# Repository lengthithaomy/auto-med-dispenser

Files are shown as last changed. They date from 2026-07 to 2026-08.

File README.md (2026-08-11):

# 💊 AutoDose — Automatic Medication Dispenser

> A standalone pill dispenser I built for the **VoltHacks Hackathon 2026**. It is designed to help people, especially elderly users, remember to take the right medication at the right time without needing a phone, Wi-Fi, or a subscription.

<p align="center">
  AutoDose device
</p>

<p align="center">
  <a href="https://youtu.be/d-JQTOUDefM?si=IusnsNRkliP58Vxm">▶️ Check out the video</a>
</p>

I designed the 3D-printed parts in **Autodesk Inventor** and wrote the firmware using the **Arduino IDE**.

Since I originally built AutoDose for use at home, I made the day labels on the tray and the reminder audio in Vietnamese. I've also included the original Inventor file, so you can modify the tray if you want to use a different language. The reminder sounds can also be replaced — see [Changing the Reminder Sound](#-changing-the-reminder-sound).

---

## 📖 What is AutoDose?

I wanted to make a pill dispenser that could do more than just remind someone that it was time to take their medication.

AutoDose stores a week's worth of morning and evening doses. At the scheduled time, it rotates the correct compartment into position and releases the pill. It then uses an IR sensor to check whether the pill was actually picked up.

If it isn't, the device keeps reminding the user every 30 minutes.

The whole thing runs locally on an Arduino. There's no app, internet connection, account, or subscription involved.

---

## ✨ Features

* 🗓️ **15-compartment rotating tray** — 14 compartments for AM/PM doses across 7 days, plus one slot used for calibration/reset.
* ⚙️ **Drift-free tray positioning** — a 7.5:1 gear reduction makes each compartment exactly 2,048 motor steps apart.
* 👁️ **Pill pickup detection** — a TCRT5000 IR sensor checks both the pill drop and whether the user has picked it up.
* 🔊 **Sound, light, and LCD reminders** — the DFPlayer Mini plays a voice reminder, while an LED and 16x2 LCD show the current status.
* ⏰ **Repeating reminders** — if the pill isn't picked up, the reminder repeats every 30 minutes.
* 🔌 **Works without the internet** — the DS3231 RTC keeps track of the time, so the dispenser doesn't need Wi-Fi or a phone.

---

## 🔩 Bill of Materials

| Component | Qty | Operating Voltage | Function |
| --- | :-: | :---: | --- |
| Arduino Uno R3 |  1  | 5V | Main controller |
| RTC DS3231 |  1  | 5V | Keeps track of the time |
| 28BYJ-48 Stepper Motor + ULN2003 Driver |  1  | 5V | Rotates the tray |
| TCRT5000 IR Reflective Sensor |  1  | 3.3–5V | Detects pill drop and pickup |
| LCD 1602 (I2C) |  1  | 5V | Shows the time and system status |
| DFPlayer Mini + 0.5W 8Ω Speaker |  1  | 3.2–5V | Plays voice reminders |
| Red LED + 220Ω Resistor |  1  | 2V | Indicates an active reminder |
| 5V USB Power Supply |  1  | 5V | Powers the device |

---

## ⚙️ Mechanical & Gear System

One of the biggest problems I ran into was keeping the tray aligned.

The 28BYJ-48 has 4,096 steps per full rotation. If the motor directly rotated the 15-slot tray, the number of steps per compartment would be:

$$
\frac{4096}{15} \approx 273.07 \text{ steps/slot}
$$

That isn't an integer, so the tray would gradually lose alignment after repeated movements.

### The 7.5:1 gear reduction

I solved this by adding a **7.5:1 gear reduction** between the motor and the tray.

That gives:

$$
4096 \times 7.5 = 30{,}720
$$

steps for one full tray rotation.

Since the tray has 15 compartments:

$$
\frac{30{,}720}{15} = 2{,}048
$$

So every compartment is exactly **2,048 motor steps** apart.

This means the motor always lands on the same position for each compartment instead of accumulating a small positioning error every time the tray moves.

---

## 🔄 How It Works

<p align="center">
  Workflow diagram
</p>

### 1. Scheduling

The Arduino checks the current time from the DS3231 against the scheduled dosing times:

* **07:00** — morning dose
* **19:00** — evening dose

### 2. Dispensing

When it's time, the stepper motor moves **2,048 steps** to bring the correct compartment above the drop chute.

### 3. Reminder

The pill falls into the receiving tray. The LED turns on and the DFPlayer Mini plays a voice reminder.

### 4. Checking if the pill was picked up

The IR sensor monitors the receiving area.

* ✅ **Pill picked up** — the system detects the change, plays a confirmation message, turns off the LED, and records the dose as completed.
* ⏳ **Pill still there** — the reminder stays active and repeats every 30 minutes until the pill is picked up.

---

## 🚀 Getting Started

1. Assemble the circuit using the components listed in the [Bill of Materials](#-bill-of-materials).
2. Upload the Arduino sketch from `/code` to the Arduino Uno.
3. Set the current date and time on the DS3231.
4. Fill the 14 medication compartments (AM/PM × 7 days). Leave the calibration slot empty.
5. Plug in the 5V USB power supply.
6. The dispenser will start checking the schedule automatically.

---

## 🔊 Changing the Reminder Sound

The reminder audio is stored on the **DFPlayer Mini**.

The included audio files are in Vietnamese because that's what I use at home. You can replace them with your own recordings if you want different languages or sounds.

See the relevant instructions in the project files for the required filenames and SD card setup.

---

## 🛠️ Things I'd Like to Improve

There are still quite a few things I'd change if I had more time:

* Add support for multiple users
* Add a battery backup so the device keeps running during a power outage
* Make different tray sizes for different medication schedules
* Add an optional caregiver app while keeping the device usable without it
* Improve the mechanical design and make the 3D-printed parts easier to assemble

---

## 📜 License

This project is licensed under the MIT License. See the [LICENSE](LICENSE) file for details.

---

## 🙏 Acknowledgments

Built for the **VoltHacks Hackathon 2026** as a first-year college project.

This started as something I wanted to make for use at home, and the hackathon gave me a good excuse to actually build it.

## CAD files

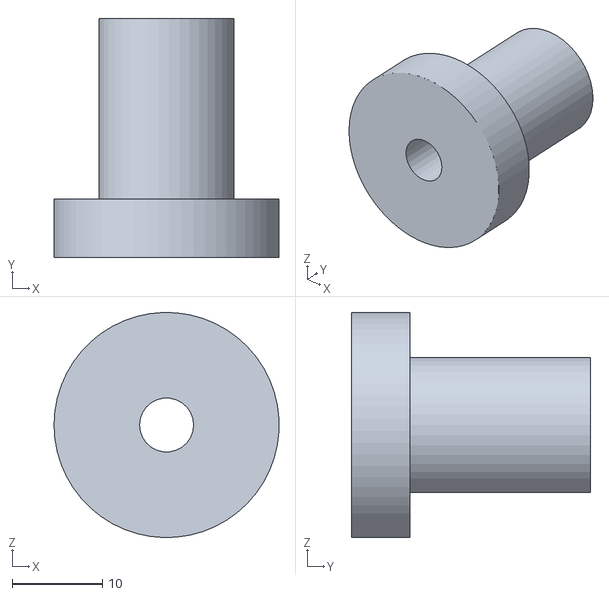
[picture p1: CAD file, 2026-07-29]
cad/stl-files/Trục-trung-tâm.stl
25.0 x 26.5 x 25.0

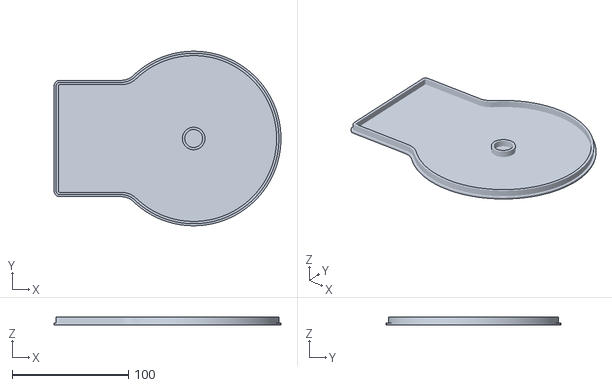
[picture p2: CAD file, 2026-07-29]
cad/stl-files/Đế.stl
195.0 x 150.0 x 6.60

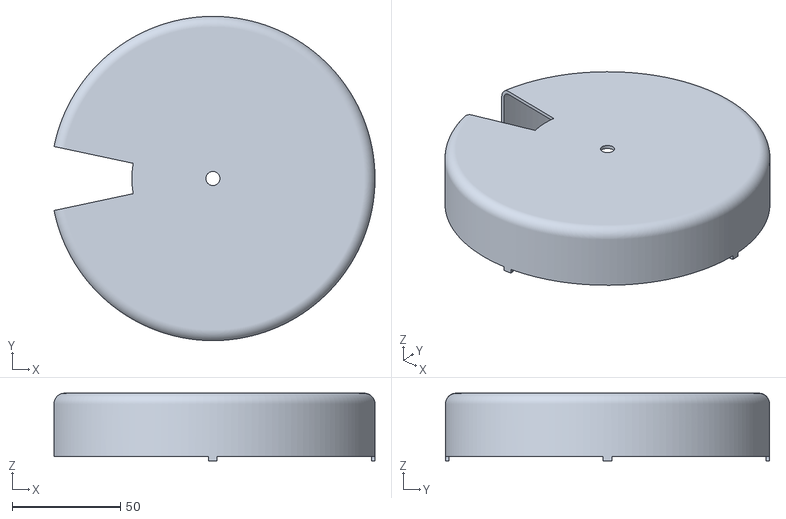
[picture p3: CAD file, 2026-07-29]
cad/stl-files/Nắp.stl
148.5 x 150.0 x 31.3

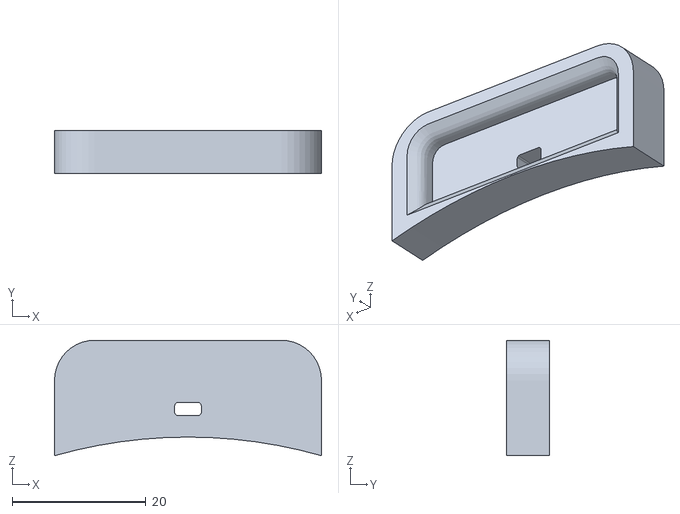
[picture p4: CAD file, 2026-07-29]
cad/stl-files/Khay-hứng-thuốc.stl
40.0 x 6.50 x 17.3

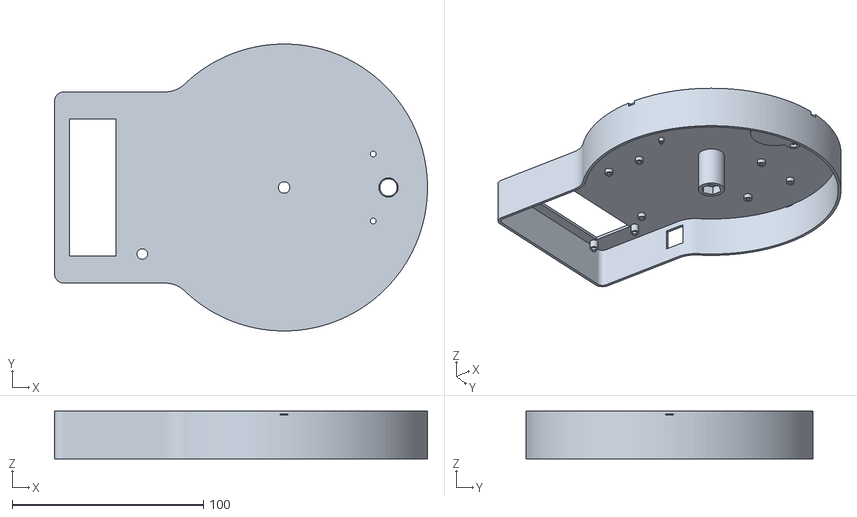
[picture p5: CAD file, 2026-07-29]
cad/stl-files/Base.stl
195.0 x 150.0 x 25.0

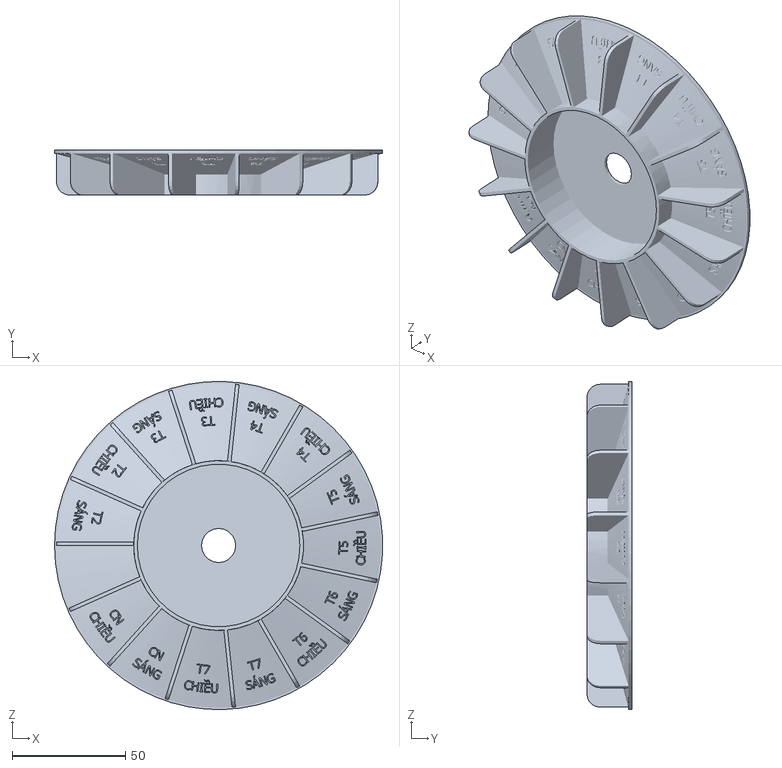
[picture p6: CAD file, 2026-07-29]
cad/stl-files/Khay-đựng.stl
144.9 x 20.0 x 144.9

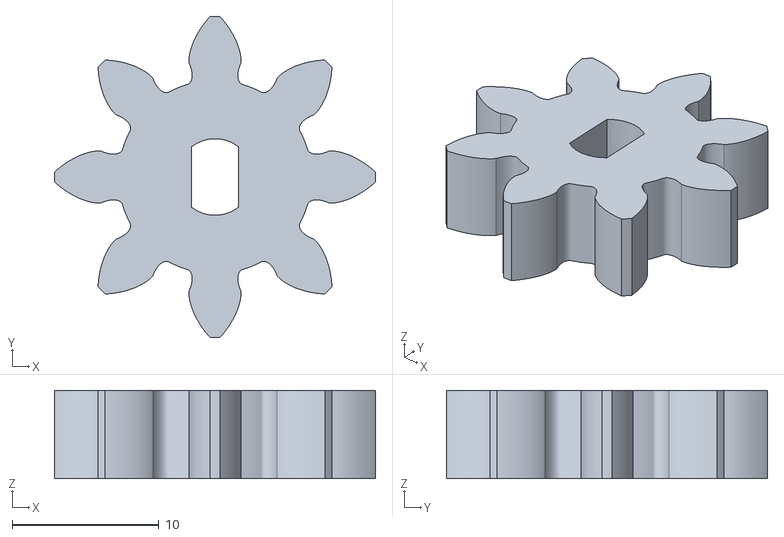
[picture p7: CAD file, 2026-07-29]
cad/stl-files/Bánh-răng-nhỏ.stl
21.8 x 21.8 x 6.00

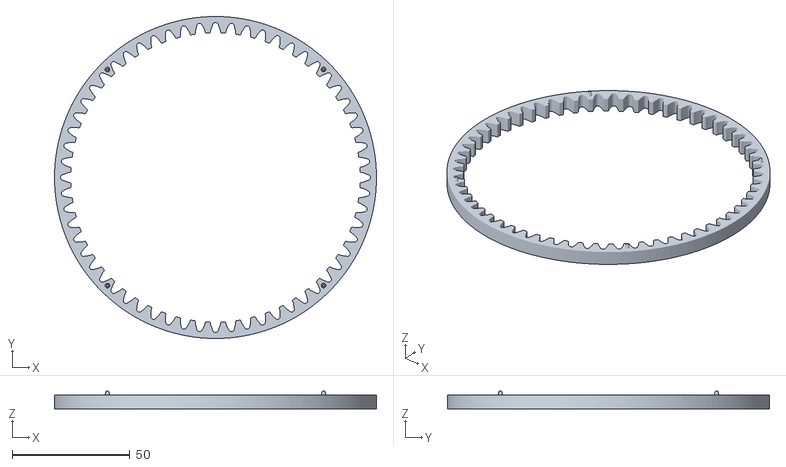
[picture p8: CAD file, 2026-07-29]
cad/stl-files/Bánh-răng-lớn.stl
136.6 x 136.6 x 7.60

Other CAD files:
cad/customize-tray/Khay-đựng.ipt

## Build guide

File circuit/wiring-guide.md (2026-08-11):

# 🔌 Circuit & Wiring

This folder contains the wiring diagram for AutoDose.

The diagram was made in Fritzing and shows how the Arduino Uno connects to the sensors, display, RTC, stepper motor, and DFPlayer Mini.

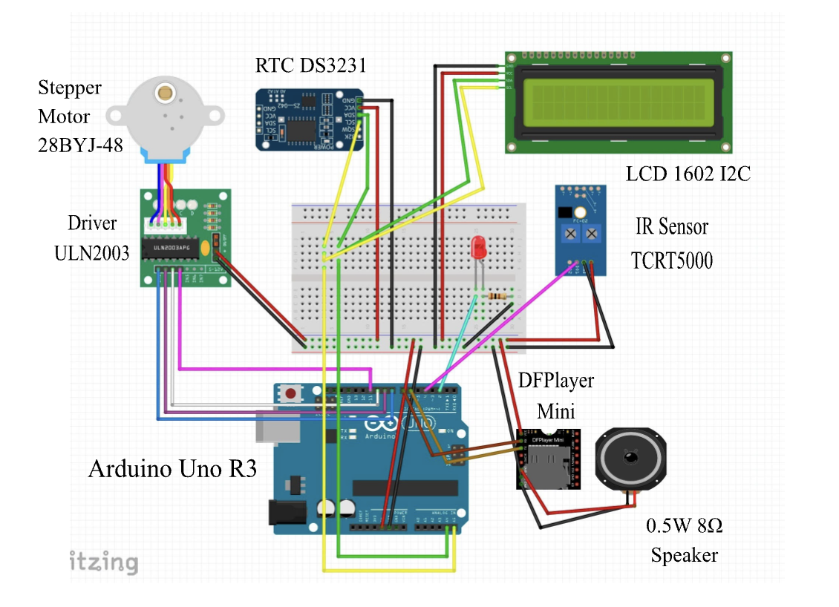
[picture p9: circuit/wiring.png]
AutoDose wiring diagram


## Pin Connections

| Component | Pin | Arduino Uno |
|---|---|---|
| ULN2003 | IN1 | D8 |
| ULN2003 | IN2 | D9 |
| ULN2003 | IN3 | D10 |
| ULN2003 | IN4 | D11 |
| TCRT5000 | OUT | D4 |
| LED | Anode (+) | D2 |
| DFPlayer Mini | RX | D7 |
| DFPlayer Mini | TX | D6 |
| DS3231 | SDA | A4 |
| DS3231 | SCL | A5 |
| LCD 1602 I2C | SDA | A4 |
| LCD 1602 I2C | SCL | A5 |

The DS3231 and LCD both use I2C, so they share the same SDA and SCL pins.

## Power

The modules are powered from the Arduino's 5V and GND connections. Make sure all modules share a common ground.

The 28BYJ-48 stepper motor is connected through the ULN2003 driver board rather than directly to the Arduino.

## Notes

The wiring shown here is based on the version of AutoDose I built for the VoltHacks Hackathon 2026. If you are rebuilding it yourself, double-check the pin connections against the Arduino code before powering everything on.

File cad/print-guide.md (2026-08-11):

# 🖨️ 3D Printing & CAD Files

AutoDose CAD model

This folder contains the 3D-printable `.stl` files I used to build AutoDose, along with the original Autodesk Inventor `.ipt` files.

I designed the parts in **Autodesk Inventor** and printed them in **PETG**. The settings below are what I used for my prints, but you may need to adjust them depending on your printer and filament.

---

## 🖨️ Print Settings

These are the general settings I used:

* **Material:** PETG
* **Layer height:** `0.2 mm`
* **Walls / Perimeters:** `3–4`
* **Infill:** Depends on the part — see the table below

The parts don't all need the same amount of infill. The gears and rotating tray, for example, need to be fairly solid, while some of the structural parts can get away with less.

---

## 📁 What's in the Folder?

| File | Filament | Infill | What it does |
| --- | --- | :----: | --- |
| `Bánh-răng-lớn.stl` | Grey | 50%  | Large gear connected to the rotating tray |
| `Bánh-răng-nhỏ.stl` | Grey | 50%  | Small gear connected to the stepper motor |
| `Trục-trung-tâm.stl`  | Grey | 50%  | Keeps the rotating tray aligned |
| `Khay-hứng-thuốc.stl` | Grey | 50%  | Tray where the pill lands after being dispensed |
| `Base.stl` | Grey | 50%  | Main housing and motor support |
| `Đế.stl` | Light Blue | 60%  | Bottom plate and support |
| `Khay-đựng.stl` | White | 80%  | 15-compartment rotating medication tray |
| `Nắp.stl` | Semi-transparent | 60%  | Top cover |

The Vietnamese filenames are just the names I used while designing the parts. Feel free to rename them if you prefer.

---

## ⚙️ A Note About the Gears

The two gears make up the **7.5:1 reduction system** used to rotate the medication tray.

The small gear is connected to the **28BYJ-48 stepper motor**, while the larger gear is connected to the tray.

This reduction is important because it gives me exactly **2,048 motor steps per compartment**, which helps keep the tray aligned.

---

## ✏️ Changing the Tray Labels

I included the original Autodesk Inventor file for the rotating tray:

```text
Khay-đựng.ipt
```

I originally made the labels in Vietnamese because this version of AutoDose is for use at home. If you're building your own version, you can change the labels to another language, different abbreviations, or whatever works for your setup.

### How to edit them

1. Open `Khay-đựng.ipt` in **Autodesk Inventor**.
2. Find the sketch/feature containing the tray labels in the Model Browser.
3. Edit the sketch and change the text.
4. Keep the text within the available space on each compartment.
5. Finish the sketch and update the model.
6. Export the updated part as an `.stl` file.
7. Open the new `.stl` in your slicer.
8. Slice it using your preferred PETG settings.

I used **Bambu Studio** for slicing, but the files should also work with other slicers such as Cura or PrusaSlicer.

For the tray, I used around **80% infill**.

---

## 🔧 A Few Things to Keep in Mind

The parts were designed around the specific components used in my build, so dimensions may need small adjustments if you're using different hardware.

In particular, check:

* The fit between the stepper motor and small gear
* The fit of the center shaft
* The spacing between the rotating tray and the base
* The clearance around the pill drop area
* The fit of the top cover

**PETG can also shrink or warp slightly depending on your printer**, so don't be surprised if you need to adjust tolerances or reprint a part.

This is still a hackathon project, so the CAD files aren't meant to be a perfect, production-ready design. They're here so you can see how I built it and hopefully make your own version.

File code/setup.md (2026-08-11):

## 💻 Software Setup & Configuration

### Prerequisites

You'll need:

* [Arduino IDE](https://www.arduino.cc/en/software) (v1.8.x or v2.x)
* Arduino Uno R3
* A USB cable
* A microSD card for the DFPlayer Mini

The following Arduino libraries are used by the project:

* `RTClib` — by Adafruit
* `LiquidCrystal_I2C`
* `DFRobotDFPlayerMini`
* `SoftwareSerial`
* `AccelStepper`

You can install these libraries through **Arduino IDE → Library Manager**.

---

### 📥 Uploading the Code

1. Clone this repository:

```bash
git clone https://github.com/your-username/automatic-medication-dispenser.git
```

2. Open the `.ino` sketch in Arduino IDE.

3. Make sure the correct board is selected:

**Tools → Board → Arduino AVR Boards → Arduino Uno**

4. Connect the Arduino Uno to your computer using USB.

5. Click **Upload**.

Once the upload is complete, AutoDose should start running as soon as the Arduino is powered.

---

### ⏰ Changing the Medication Schedule

The default schedule is:

* **07:00:00** — morning medication
* **19:00:00** — evening medication

You can change these times near the top of the code:

```cpp
// Time setting
int amHr = 7,  amMin = 0, amSec = 0;
int pmHr = 19, pmMin = 0, pmSec = 0;
```

For example, to change the morning dose to 8:30 AM:

```cpp
int amHr = 8, amMin = 30, amSec = 0;
```

The values use the 24-hour clock.

---

### 🕐 Setting the RTC Time

The DS3231 keeps track of the date and time even when the Arduino isn't actively checking the schedule.

To manually set it:

1. Upload the code and connect the Arduino to your computer.
2. Open **Serial Monitor** in Arduino IDE.
3. Set the baud rate to **9600**.
4. Type:

```text
u
```

5. The Arduino will ask for the following values one at a time:

```text
year
month
day
hours
minutes
seconds
```

For example:

```text
2026
8
11
14
30
00
```

The RTC will then be updated with the new date and time.

If you want to cancel the process, enter:

```text
-1
```

---

## 🔊 Changing the Reminder Sound

AutoDose uses a **DFPlayer Mini** to play the voice reminders. The audio files are stored on a microSD card inserted into the DFPlayer Mini.

The current code expects the following folder structure:

```text
SD Card
├── 01
│   └── 001.mp3
└── 02
    └── 001.mp3
```

### 🌅 Morning reminder

The morning sound is loaded from:

```text
/01/001.mp3
```

This is triggered by:

```cpp
myDFPlayer.playFolder(1, 1);
```

### 🌇 Evening reminder

The evening sound is loaded from:

```text
/02/001.mp3
```

This is triggered by:

```cpp
myDFPlayer.playFolder(2, 1);
```

### 🎵 Adding your own sounds

To replace the default Vietnamese reminders:

1. Prepare a **microSD card** supported by the DFPlayer Mini.
2. Format the card as **FAT32**.
3. Create two folders in the root of the SD card:

```text
01
02
```

4. Put your morning reminder in:

```text
01/001.mp3
```

5. Put your evening reminder in:

```text
02/001.mp3
```

6. Insert the SD card into the DFPlayer Mini.
7. Restart AutoDose and test both scheduled times.

The files should be **MP3 audio files**. Keeping the filenames as `001.mp3` and the folder names as `01` and `02` is important because the Arduino code specifically looks for those locations.

You can record your own voice, use another language, or replace the reminder with a simple sound.

### 🔊 Changing the volume

The volume is controlled in `setup()`:

```cpp
myDFPlayer.volume(30);
```

The DFPlayer Mini uses a volume range from **0 to 30**.

For example:

```cpp
myDFPlayer.volume(20);
```

would make the reminder quieter.

---

## 🧪 How the Reminder System Works

When the scheduled time is reached, the Arduino:

1. Moves the tray by **2,048 steps**.
2. Turns on the LED.
3. Plays the corresponding audio file from the DFPlayer Mini.
4. Waits for the TCRT5000 sensor to detect whether the pill has been picked up.

When the sensor changes from `LOW` to `HIGH`, the Arduino considers the medication to have been taken, turns off the LED, and displays:

```text
Da uong thuoc
```

on the LCD.

The current version **does not repeat the audio reminder automatically**. The sound is played once when the medication is dispensed, while the LED remains on until the pill is picked up.

---

## 📝 A Note About the Current Firmware

The code in this repository is the version I used for the hackathon project, so some parts are intentionally simple.

For example, the AM and PM doses have their own state variables:

```cpp
amDispensed
amShown
amTaken

pmDispensed
pmShown
pmTaken
```

This prevents the system from repeatedly dispensing the same dose during the same scheduled second.

After a dose is picked up, the LCD message is cleared after 5 minutes:

```cpp
if (amTaken && millis() - takenTimestamp >= 300000)
```

The same logic is used for the evening dose.

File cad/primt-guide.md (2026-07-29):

 # 3D Printing & CAD Design Files
 


This directory contains all 3D print model files (`.stl`) and CAD source files (`.ipt`) for the **Smart Automatic Medication Dispenser**.

---

## File Directory & Recommended Slicer Settings

### General Print Settings
- **Filament Material:** PETG
- **Layer Height:** `0.2 mm`
- **Walls / Perimeters:** 3–4 wall loops

### File List & Component Breakdown

| File Name | Color / Filament | Infill Density | Description / Function |
| :--- | :--- | :---: | :--- |
| **`Bánh-răng-lớn.stl`** | Grey | 50% | Driven gear attached to the rotating tray (7.5:1 ratio) |
| **`Bánh-răng-nhỏ.stl`** | Grey | 50% | Pinion gear attached to the 28BYJ-48 stepper motor shaft |
| **`Trục-trung-tâm.stl`** | Grey | 50% | Central alignment axle / shaft |
| **`Khay-hứng-thuốc.stl`** | Grey | 50% | Receiving tray / output chute where dispensed pills drop |
| **`Base.stl`** | Grey | 50% | Main structural housing for components & motor mount |
| **`Đế.stl`** | Light Blue | 60% | Bottom base plate and support structure |
| **`Khay-đựng.stl`** | White | 80% | 15-compartment rotating medication tray |
| **`Nắp.stl`** | Semi-transparent | 60% | Top protective cover / lid |

---

## Customizing Tray Labels (`.ipt` Source File)

The CAD source file **`Khay-đựng.ipt`** (Autodesk Inventor) is provided to edit or customize the day/time labels engraved or raised on the tray (e.g., changing from AM/PM to custom languages or symbols).

### Editing Steps:
1. Open **`Khay-đựng.ipt`** in **Autodesk Inventor** (2020 or newer).
2. In the Model Browser tree (left panel), locate and right-click on **`Sketch_Labels`** / **`Extrude_Text`**.
3. Select **Edit Sketch** to modify the text strings, fonts, or embossing depth.
4. Export the updated model: Go to `File` ➔ `Export` ➔ `CAD Format` and select `.stl`.
5. Import the newly exported `.stl` into your Slicer (Cura, PrusaSlicer, Bambu Studio) and slice using **80% Infill** with **PETG**.

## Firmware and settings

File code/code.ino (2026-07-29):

#include <Arduino.h>
#include <Wire.h>
#include <LiquidCrystal_I2C.h>
#include <RTClib.h>
#include <AccelStepper.h>
#include <SoftwareSerial.h>
#include <DFRobotDFPlayerMini.h>

// ---------------- LCD ----------------
LiquidCrystal_I2C lcd(0x27, 16, 2);

// ---------------- RTC ----------------
RTC_DS3231 rtc;

// ---------------- Stepper Motor ----------------
#define motorPin1  8
#define motorPin2  9
#define motorPin3  10
#define motorPin4  11
#define MotorInterfaceType 8
AccelStepper stepper = AccelStepper(MotorInterfaceType, motorPin1, motorPin3, motorPin2, motorPin4);

// ---------------- DFPlayer Mini ----------------
SoftwareSerial mySoftwareSerial(6, 7); // RX, TX
DFRobotDFPlayerMini myDFPlayer;

// ---------------- Time setting ----------------
int amHr = 7, amMin = 0, amSec = 0;
int pmHr = 19, pmMin = 0, pmSec = 0;

// ---------------- Constants ----------------
const int led = 2;
const int sensorPin = 4;   // TRTC5000

// ---------------- Variables ----------------
int sensorState = 0;

// --- state flags ---
bool amDispensed = false;
bool amShown = false;
bool amTaken = false;

bool pmDispensed = false;
bool pmShown = false;
bool pmTaken = false;

unsigned long takenTimestamp = 0;

// ---------------- VALIDATION ----------------
typedef struct minMax_t {
  int minimum;
  int maximum;
};

bool checkInput(const int value, const minMax_t minMax) {
  if (value >= minMax.minimum && value <= minMax.maximum)
    return true;

  Serial.print(value);
  Serial.print(" is out of range ");
  Serial.print(minMax.minimum);
  Serial.print(" - ");
  Serial.println(minMax.maximum);
  return false;
}

// ---------------- UPDATE RTC ----------------
void updateRTC() {
  lcd.clear();
  lcd.setCursor(0, 0);
  lcd.print("Edit Mode...");

  const char txt[6][15] = {
    "year [4-digit]", "month [1~12]", "day [1~31]",
    "hours [0~23]", "minutes [0~59]", "seconds [0~59]"
  };

  const minMax_t minMax[] = {
    {2000, 9999}, {1, 12}, {1, 31},
    {0, 23}, {0, 59}, {0, 59},
  };

  String str = "";
  long newDate[6];
  DateTime newDateTime;

  while (1) {
    while (Serial.available()) Serial.read();

    for (int i = 0; i < 6; i++) {
      while (1) {
        Serial.print("Enter ");
        Serial.print(txt[i]);
        Serial.print(" (or -1 to abort) : ");

        while (!Serial.available());
        str = Serial.readString();

        if (str == "-1" || str == "-1\n" || str == "-1\r" || str == "-1\r\n") {
          Serial.println("\nABORTED");
          return;
        }

        newDate[i] = str.toInt();
        if (checkInput(newDate[i], minMax[i])) break;
      }
      Serial.println(newDate[i]);
    }

    newDateTime = DateTime(
      newDate[0], newDate[1], newDate[2],
      newDate[3], newDate[4], newDate[5]
    );

    if (newDateTime.isValid()) break;
    Serial.println("Date/time invalid, try again.");
  }

  rtc.adjust(newDateTime);
  Serial.println("RTC Updated!");
}

// ---------------- UPDATE LCD ----------------
void updateLCD() {
  DateTime rtcTime = rtc.now();
  char timeBuffer[] = "hh:mm:ss";

  lcd.setCursor(0, 0);
  lcd.print(" TG: ");
  lcd.setCursor(5, 0);
  lcd.print(rtcTime.toString(timeBuffer));
}

// ---------------- ROTATE MOTOR ----------------
void rotateMotor() {
  stepper.enableOutputs();
  stepper.setCurrentPosition(0);

  while (stepper.currentPosition() != -2048) {
    stepper.setSpeed(-500);
    stepper.runSpeed();
  }
  stepper.disableOutputs();

  digitalWrite(led, HIGH);  // LED sáng lúc thuốc rơi
}

// ---------------- ROTATE AM ----------------
void rotateAM() {
  rotateMotor();
  amDispensed = true;
  amShown = false;
  amTaken = false;

  // Phát âm thanh buổi sáng sau khi motor quay xong
  myDFPlayer.playFolder(1, 1); // Folder 01, file 001.mp3
  Serial.println("Chao buoi sang");
}

// ---------------- ROTATE PM ----------------
void rotatePM() {
  rotateMotor();
  pmDispensed = true;
  pmShown = false;
  pmTaken = false;

  // Phát âm thanh buổi chiều sau khi motor quay xong
  myDFPlayer.playFolder(2, 1); // Folder 02, file 001.mp3
  Serial.println("Chao buoi chieu");

}

// ---------------- SETUP ----------------
void setup() {
  stepper.setMaxSpeed(1000);

  Serial.begin(9600);

  // LCD setup
  lcd.init();        // chắc chắn LCD được init
  lcd.backlight();   // bật đèn nền
  lcd.clear();
  lcd.setCursor(0, 0);
  lcd.print("Khoi dong..."); // test chữ hiển thị

  rtc.begin();

  pinMode(led, OUTPUT);
  pinMode(sensorPin, INPUT);

  // ---------------- DFPlayer Setup ----------------
  mySoftwareSerial.begin(9600);
  if (!myDFPlayer.begin(mySoftwareSerial)) {
    Serial.println(F("Khong ket noi duoc DFPlayer Mini!"));
    while(true);
  }
  myDFPlayer.volume(30); // âm lượng 0~30
}

// ---------------- LOOP ----------------
void loop() {
  DateTime rtcTime = rtc.now();
  updateLCD();

  sensorState = digitalRead(sensorPin);  // LOW = có thuốc

  // ----------- AM DISPENSE -----------
  if (rtcTime.hour() == amHr && rtcTime.minute() == amMin && rtcTime.second() == amSec) {
    lcd.clear();
    rotateAM();
  }

  if (amDispensed && !amTaken) {
    if (sensorState == LOW && !amShown) {
      lcd.setCursor(0, 1);
      lcd.print("Thuoc buoi sang ");
      amShown = true;
    }

    if (sensorState == HIGH && amShown) {
      lcd.setCursor(0, 1);
      lcd.print(" Da uong thuoc   ");
      digitalWrite(led, LOW);
      amTaken = true;
      takenTimestamp = millis();
    }
  }

  if (amTaken && millis() - takenTimestamp >= 300000) { // 5 phút
    lcd.setCursor(0, 1);
    lcd.print("                ");
  }

  // ----------- PM DISPENSE -----------
  if (rtcTime.hour() == pmHr && rtcTime.minute() == pmMin && rtcTime.second() == pmSec) {
    lcd.clear();
    rotatePM();
  }

  if (pmDispensed && !pmTaken) {
    if (sensorState == LOW && !pmShown) {
      lcd.setCursor(0, 1);
      lcd.print("Thuoc buoi chieu");
      pmShown = true;
    }

    if (sensorState == HIGH && pmShown) {
      lcd.setCursor(0, 1);
      lcd.print(" Da uong thuoc   ");
      digitalWrite(led, LOW);
      pmTaken = true;
      takenTimestamp = millis();
    }
  }

  if (pmTaken && millis() - takenTimestamp >= 300000) {
    lcd.setCursor(0, 1);
    lcd.print("                ");
  }

  // ----------- SERIAL KEPT ORIGINAL -----------
  if (Serial.available()) {
    char input = Serial.read();
    if (input == 'u') updateRTC();
  }
}

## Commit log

2026-07-29 Create 3d-printed-stl
2026-07-29 Update and rename 3d-printed-stl to cad
2026-07-29 Create stl-files
2026-07-29 Update stl-files
2026-07-29 Create circuit
2026-07-29 Rename Screenshot 2026-07-30 at 01.22.46.png to wiring.png
2026-07-29 更新 README.md
2026-07-29 更新 print-guide.md
